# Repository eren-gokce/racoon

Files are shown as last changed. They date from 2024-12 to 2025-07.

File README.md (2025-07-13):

# Roket Aviyonik 🚀

### Güncel :

<details> <summary> Watchdog </summary>

Interrupt Watchdog (IWDT)
RTC Watchdog Timer (RTC_WDT)

ESP32 mimarisinde iki önemli sistem watchdog’u olan Interrupt Watchdog (IWDT) ve RTC Watchdog Timer (RTC_WDT), 
uygulama koduna herhangi bir müdahaleye gerek kalmadan sistem seviyesinde otomatik olarak çalışmaktadır.
IWDT, FreeRTOS işletim sistemi tarafından her tick’te beslenerek, ISR’ların veya kritik bölümlerin sistemin kilitlenmesine neden olup olmadığını denetler. 
RTC_WDT ise, sistem açıldığında (boot aşamasında) devreye girerek, main() fonksiyonuna zamanında ulaşılamazsa otomatik reset işlemi gerçekleştirir. 
Bu iki watchdog, ESP32 sisteminin kararlı çalışmasını sağlamakta, olası kilitlenmelerde sistemin kendi kendine toparlanmasına imkân tanımaktadır.

Task Watchdog Timer (TWDT)

ESP32 platformunda kullanılan Task Watchdog Timer (TWDT), belirli görevlerin (task'ların) belirli bir süre içerisinde düzgün şekilde 
çalışıp çalışmadığını denetlemek amacıyla kullanılan bir yazılımsal koruma mekanizmasıdır. 
Kullanıcı tarafından başlatılarak aktif hâle getirilen TWDT’ye, izlenmesi istenen görevler abone edilir. 
Bu görevler, belirlenen zaman aralığında esp_task_wdt_reset() fonksiyonu ile watchdog'u “beslemeli”; aksi takdirde 
TWDT bu görevin kilitlendiğini varsayarak sistemin hata mesajı üretmesini (panic) ya da resetlenmesini sağlar.
Güvenlik-kritik uygulamalarda TWDT, sistemin ana görevlerinin donması, veri akışının kesilmesi veya 
infinite loop gibi yazılım hatalarının oluşması durumunda müdahale ederek sistemin kendi kendini kurtarabilmesini sağlar.

```cpp
#include "esp_task_wdt.h"

void setup() {
  // ... mevcut kurulumlar ...

  esp_task_wdt_config_t twdt_config = {
    .timeout_ms = 3000, // 3 saniye içinde resetlenmeli
    .idle_core_mask = 0, // idle task izlenmiyor
    .trigger_panic = true
  };

  esp_task_wdt_init(&twdt_config); // Watchdog’u başlat
  esp_task_wdt_add(NULL);          // Mevcut görev (loop task) TWDT’ye abone edildi
}

void loop() {
  // Uçuş kontrol fonksiyonlarını çağır
  kalkis();
  burnout();
  apogee();
  parasut();
  alcalma();
  call_lora();

  esp_task_wdt_reset(); // 🔁 watchdog'u besle

  delay(200);
}
```
</details>

## [Yapılcaklar notu](https://ostimteknikuniversitesi-my.sharepoint.com/:w:/g/personal/230201060_ostimteknik_edu_tr/EbsuAKLU0ShNoTfdPXoBlwgBV6bBdwqXOMXw21tmuLnfXQ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)

<details> <summary> old  </summary>

güncel Algo flowchart
güncel Algo flowchart
	
- [Eski Arayüz Reposu](https://github.com/CerenSultanCETIN/RocketInterface13.git)

<div style="display: flex; justify-content: center; gap: 20px;">
  <a href="https://github.com/user-attachments/assets/b3c92df3-6dc9-4abe-9a28-f702d46e05a6">
    resim1
  </a>
<div style="display: flex; justify-content: center; gap: 20px;">
  <a href="https://github.com/user-attachments/assets/648fd35b-3c85-447b-8fb1-8ce616d4887b">
    resim1
  </a>

### 2025.04.27 KTR şablonundan olan görevlerim : 

- Özgün UKB’lerin algoritmaları açık ve net bir şekilde açıklanmalıdır.
 Algoritma açıklanırken karmaşık ve uzun cümleler kullanılmamalı,
 akış şemaları kullanılmalıdır. 
Kullanılan algoritmaya ilişkin akış şemasında; 
algoritmada kullanılan parametrelerin hangi sensörden geldiği açık ve net bir şekilde anlatılmalıdır.
 Kurtarma sistemini tetikleyecek parametreler listelenmeli ve neden seçildiği belirtilmelidir (kullandığı parametreleri doğru sensörlerden almayan veya eksik olarak açıklayan takımlar diskalifiye edilecektir). 
Algoritma içerisinde haberleşme ve yer istasyonu ile ilgili adımlar var ise bunlar paylaşılmamalıdır.
 (besma // görselleştirerek yap)

- Özgün UKB’lerin test edilmesi kapsamında test cihazı ile Ö-UKB arasında çalışacak olan yazılımın UKB ana algoritması ile nasıl entegre edildiği ve çalışma yapısı açık şekilde algoritma şeması olarak paylaşılmalıdır. (semih/enes/besma)

### 2025.04.26
Deney videosu (Semih) 
https://drive.google.com/drive/folders/1odC9xmdg6W0WZIL8I4gqv5UqY6kFndTy?usp=sharing

### 2025.04.24 Mete başkana algoritma hakkında soru soruldu ve bunun çıktısı şöyle oldu : 

🌟 Özet Strateji:

🧠 Sensör Füzyonlama (Sensor Fusion) + 📉 Kalman Filtresi

Bu iki yöntem, farklı sensörlerden gelen verileri birleştirerek daha doğru ve güvenilir ölçümler sağlar.

⸻

💡 Elimizdeki Üç Faktör:
	1.	İvme (Accelerometer)
	•	Başlangıç ve motor bitimi (burn-out) sırasında yüksek titreşim nedeniyle barometre bozulabilir.
	•	Bunu kontrol etmek için ivmeölçer (accelerometer) kullanılır.
	•	Kalman filtresi ile filtrelenerek anlık ivme patlamalarına karşı önlem alınır.
	2.	Dikey Hız (Vertical Speed)
	•	Barometre verisinden veya ivme verisinin integralinden hesaplanabilir.
	•	Özellikle motor kapanışından sonra roketin apogee noktasına ulaşıp ulaşmadığı burada anlaşılır.
	3.	Yükseklik (Altitude)
	•	Barometrik sensör (BMP280 gibi) ile ölçülür ama burn-out ve ani basınç değişimlerinde güvenilirliği düşer.
	•	Bu nedenle ivme ve dikey hız verisiyle çapraz kontrol yapılır.

⸻

🔍 Neden Kalman Filtresi?

Kalman filtresi, sistemdeki gürültülü sensör verilerini birleştirerek en iyi tahmini yapar. Yani:
	•	Barometre + ivmeölçer verisi → Yükseklik ve dikey hızın en güvenilir hali elde edilir.
	•	Başlangıçta barometredeki hataları ivme ile check edersiniz.
	•	Hata varsa Kalman filtresi bunu “güvenilir olmayan veri” olarak değerlendirip tahminini düzeltir.

⸻

🔄 Sensör Füzyonlama
	•	Sensör füzyonlama, farklı kaynaklardan gelen verileri birleştirerek tek bir anlamlı veri seti üretir.
	•	Örneğin:
	•	BMP280 (yükseklik)
	•	MPU6050 (ivme ve gyro)
	•	Kalman filtresi ile bu sensörlerin birleşimi yapılır.

⸻

📌 Uygulamada Ne Yapılmalı?
	1.	MPU6050 → ivme ve gyro verisini oku.
	2.	BMP280 → basınca dayalı yükseklik verisini al.
	3.	Tüm bu verileri Kalman filtresi ile işleyerek:
	•	Gerçek yükseklik
	•	Dikey hız
	•	Apogee tespiti
gibi önemli bilgileri güvenilir şekilde elde et.

---

📌 KTR Raporunda Algoritma’dan Ne Bekleniyor?

- 📄 “Özgün UKB’lerin algoritmaları açık ve net bir şekilde açıklanmalıdır.”
- 📄 “Algoritma açıklanırken karmaşık ve uzun cümleler kullanılmamalı, akış şemaları kullanılmalıdır.”
- 📄 “Algoritmada kullanılan parametrelerin hangi sensörden geldiği açık ve net bir şekilde anlatılmalıdır.”
- 📄 “Kurtarma sistemini tetikleyecek parametreler listelenmeli ve neden seçildiği belirtilmelidir.”
- 📄 “Algoritma içerisinde haberleşme ve yer istasyonu ile ilgili adımlar var ise bunlar paylaşılmamalıdır.”

### 2025.04.20 / Algoritma Deney Testi / Asansör Kullanıldı hızın değişimi gözlemlendi. ( Erenle birlikte yaptık )
##### KTR de bu kısımda bizden istenilen şu şekilde yazılmış: 

- Algoritma Testleri:
Bu test ile takimlar özgün UKB'leri ile aym sensör mimarisine sahip bir prototip olusturmalidir. Prototip için devre kartinin üretilmis olmasi gerekmemektedir. Sensörler modül olarak breadboard üzerinde bir araya getirilebilir. Devre kartini üretmis olan takimlar nihai devre kartlari ile bu testi gerçeklestirebilirler.
Testin amaci ayrilma sistemini aktiflestirecek olan algoritmanin çalisma prensibinin kontrolüdür. Takimlar gerekirse algoritmalari için belirledikleri esik degerleri degistirerek ancak algoritma mantigini degistirmeden algoritmalarin1 test etmelidirler. Yapilan test sonucunda ayrilma sisteminin aktiflestirildigi görsel veya isitsel bir çikti ile gösterilmelidir.
Ornek bir test senaryosu olarak, ayrilma algoritmasinda roketin yer normali ile yaptigi açi ve irtifa degerini kullanan bir sistem için breadboard üzerine yerlestirilen bir prototip aviyonik sistemin yer ile yaptigi açi el ile degistirilebilir.
Sonrasinda ise sistem bir emis sistemi (örnegin elektrik süpürgesi) yardimiyla vakumlama yapip irtifa degisimi saglanabilir. Yapilan degisiklikler sonucun kurtarma sisteminin aktivasyonunu modellemek için bir LED lambas1 yakilabilir ya da bir ses sistemi (örnegin buzzer) aktive edilebilir. Yapilan bu adimlar en fazla 30 saniyelik bir video ile gösterilmelidir.

  https://github.com/user-attachments/assets/4e7f96be-68da-4bf2-be7a-c1ad1da02b06

  - BUNUN SESLENDİRİLMESİ YAPILMASI GEREKİYOR ASANSÖRDE ÇIKILDIĞINI VE ŞU AMAÇLA YAPILMASI GEREKTİĞİNİ SÖYLEYEN BİR MONTAJ 

<a href="https://github.com/user-attachments/assets/b571d8d4-8fc2-40d7-b4c7-0fd44b211a0b">
  
</a>
<a href="https://github.com/user-attachments/assets/4e7f96be-68da-4bf2-be7a-c1ad1da02b06">
  
</a>

### 💥 2025.03.15 / KTR Raporlarının hazırlanması 

#### Questions:

1. Kodlanış şekilleri, i2c mi SPI mı UART mı ?
2. Hazır kütüphane var mı yoksa driver mı yazılacak ?

<details> <summary> Alternatif Modül</summary> 
2025_01_25/27

GPS için araştırma sürecine girdim ancak araştırırken birkez daha aldığım GPS modülunu denemeye karar verdim, başka bir kodla EKTEDİR, Cerendeydi GPS getirdi bende test için eve getirdim. Pazartesi günü Yusuf ve Şenol hocalarla konuşmak için gideceğim Ömer de eşlik edecek inşallah o güne kadar detaylı bir GPS modül araştırma raporlamasını yapmış olur test etmiş olurum yeni kodu umarım lock olur. 

- [NEO-6M GPS MODÜL ile konum, hız, irtifa, tarih bilgisi alma | ESP VE ARDUİNO | TİNYGPS++ LİBRARY](https://www.youtube.com/watch?v=yDfn9ZEc5MA)
- [Videodaki verilen kod](https://drive.google.com/drive/folders/1Ig9ccjL5o0V9VCOxEw0sJ4Tpg6B3VTsB)
- [TinyGPS++ Library](https://github.com/mikalhart/TinyGPSPlus?tab=readme-ov-file)

--
{Elimizdeki GY-NEO6MV2 GPS Modülü}
Roket takımları genelde Adafruit Ultimate GPS Modülü veya elimizdeki GY-NEO6MV2 GPS Modülünü kullanmış 
benim beğendiğim  u-blox NEO-M8N-0 
---
Alternatif Modüller :
-----------------------------

Adafruit Ultimate GPS 

[ Adafruit Ultimate GPS Breakout - 66 channel w/10 Hz updates: Bu modül, yüksek hassasiyetli GPS verileri sağlar ve 10 Hz'e kadar güncelleme hızı sunar. Ayrıca, dahili veri kaydedici ve antene sahiptir.
](https://www.adafruit.com/product/5440)
----------------------------------------------------- --------
[ Adafruit Ultimate GPS Breakout with GLONASS + GPS - PA1616D: Bu model, hem GPS hem de GLONASS uydu sistemlerini destekler, bu sayede daha hızlı ve hassas konum belirleme imkanı sunar.](https://www.adafruit.com/product/746?utm_source=chatgpt.com)

Ublox GYGPSV1 NEO-8M GPS Modülü:
1. [Ublox GY-GPSV3 NEO-8M M8N GPS Modülü](https://www.robocombo.com/ublox-gy-gpsv3-neo-8m-m8n-gps-modulu--3196) 472,56 ₺

2. [u-blox NEO-M8N-0](https://www.mouser.com.tr/ProductDetail/u-blox/NEO-M8N-0?qs=zW32dvEIR3unZhZI0KRbew%3D%3D
)[DataSheet](https://www.mouser.com.tr/datasheet/2/1025/NEO_M8_FW3_DataSheet_UBX_15031086-3180589.pdf)

Beitian BN-220 GPS Modülü
1. [AddictiveRC](https://shop.addictiverc.com/products/beitian-bn-220-gps-module-3-6v-5-5v-ttl-level-dual-gnss-module-built-in-led-flash-for-rc-fpv-drone) $20

2. [AMAZON](https://www.amazon.com.tr/Rordigo-HMC5883-Glonass-Kurulum-Kullan%C4%B1m/dp/B0D37YDZNM) 845 ₺
   
3. [Beitian Dual BN-220 GPS GLONASS Anten Modülü TTL Seviye RC Drone Uçak](https://www.elecbee.com/tr-592-GPS-Module/tr-17610-Beitian-Dual-BN-220-GPS-GLONASS-Antenna-Module-TTL-Level-RC-Drone-Airplane 
)$17,59

4. [Tyro119 RC Drone FPV Yarışı için Beitian BN-220T GPS Modülü Çift Modülü](https://www.elecbee.com/tr-617-module-board/tr-17651-Beitian-BN-220T-GPS-Module-Dual-Module-for-Tyro119-RC-Drone-FPV-Racing) $14,32

Ublox ZED-F9P RTK GPS Modülü

-------------------------------------
başka gps modüllerine burdan bakabiliriz : 
https://www.mouser.com.tr/c/embedded-solutions/wireless-rf-modules/gnss-gps-modules/

---
</details>

-----

| **GPS Modülü** | **Kullanılan Protokoller** | **Hazır Kütüphane** | **Yazılım Platformu** | **Driver Gereksinimi** |
| --- | --- | --- | --- | --- |
| **Adafruit Ultimate GPS Breakout** | UART | **Adafruit GPS Kütüphanesi** ([GitHub](https://github.com/adafruit/Adafruit_GPS)) | Arduino, Python | Hayır, kütüphane mevcut. |
|  |  | **TinyGPS++ Kütüphanesi** ([GitHub](https://github.com/mikalhart/TinyGPSPlus)) | Arduino, ESP32, ESP8266 | Hayır, kütüphane mevcut. |
| **Adafruit Ultimate GPS + GLONASS (PA1616D)** | UART | **Adafruit GPS Kütüphanesi** ([GitHub](https://github.com/adafruit/Adafruit_GPS)) | Arduino, Python | Hayır, kütüphane mevcut. |
|  |  | **TinyGPS++ Kütüphanesi** ([GitHub](https://github.com/mikalhart/TinyGPSPlus)) | Arduino, ESP32, ESP8266 | Hayır, kütüphane mevcut. |
| **Ublox GY-GPSV3 NEO-8M** | UART | **u-blox C++/Python API** ([u-blox Docs](https://www.u-blox.com/en/docs/UBX-13003221)) | Arduino, STM32, Raspberry Pi, Python | Hayır, kütüphane mevcut. |
|  |  | **TinyGPS++ Kütüphanesi** ([GitHub](https://github.com/mikalhart/TinyGPSPlus)) | Arduino, ESP32, ESP8266 | Hayır, kütüphane mevcut. |
|  |  | **NeoGPS Kütüphanesi** ([GitHub](https://github.com/SlashDevin/NeoGPS)) | Arduino, AVR, ESP8266 | Hayır, kütüphane mevcut. |
| **Ublox NEO-6M GPS Modülü** | UART | **TinyGPS++ Kütüphanesi** ([GitHub](https://github.com/mikalhart/TinyGPSPlus)) | Arduino, ESP32, ESP8266, STM32 | Hayır, kütüphane mevcut. |
|  |  | **NeoGPS Kütüphanesi** ([GitHub](https://github.com/SlashDevin/NeoGPS)) | Arduino, AVR, ESP8266 | Hayır, kütüphane mevcut. |
|  |  | **u-blox C++/Python API** ([u-blox Docs](https://www.u-blox.com/en/docs/UBX-13003221)) | Arduino, Raspberry Pi, STM32, Python | Hayır, kütüphane mevcut. |
| **Beitian BN-220 GPS Modülü** | UART | **TinyGPS++ Kütüphanesi** ([GitHub](https://github.com/mikalhart/TinyGPSPlus)) | Arduino, ESP32, ESP8266 | Hayır, kütüphane mevcut. |
|  |  | **NeoGPS Kütüphanesi** ([GitHub](https://github.com/SlashDevin/NeoGPS)) | Arduino, AVR, ESP8266 | Hayır, kütüphane mevcut. |
| **Ublox ZED-F9P RTK GPS Modülü** | UART, I2C, SPI | **u-blox F9P RTK Kütüphanesi** ([u-blox Docs](https://www.u-blox.com/en/docs/UBX-21022705)) | Arduino, Raspberry Pi, STM32, Python | Hayır, kütüphane mevcut. |
|  |  | **TinyGPS++ Kütüphanesi** ([GitHub](https://github.com/mikalhart/TinyGPSPlus)) | Arduino, ESP32, ESP8266 | Hayır, kütüphane mevcut. |

### **Kütüphaneler ve Kullanım Alanları:**
| **Kütüphane** | **Platformlar** | **Avantajlar** | **Olası Sorunlar** |
| --- | --- | --- | --- |
| **TinyGPS++** | Arduino, ESP32, ESP8266 | Basit ve hızlı kullanım. Hızlı entegrasyon sağlar. | Bellek kısıtlaması olan projelerde yetersiz olabilir, örneğin düşük bellekli cihazlarda. |
| **NeoGPS** | Arduino, AVR, ESP8266 | Düşük bellek kullanımı, hızlı veri işleme. Gerçek zamanlı verileri işlemek için optimize edilmiştir. | Yapılandırması daha karmaşık olabilir, başlangıç seviyesindeki kullanıcılar için zorlayıcı olabilir. |
| **u-blox API** | Arduino, STM32, Raspberry Pi | Gelişmiş veri işleme, GNSS desteği, yüksek doğruluklu veriler sağlar. | Basit projelerde fazla karmaşık ve donanım gereksinimleri yüksek olabilir. Ayrıca, API'yi kullanmak için biraz daha fazla öğrenme süresi gerekebilir. |
| **u-blox F9P RTK** | Arduino, STM32, Raspberry Pi | RTK (Real-Time Kinematic) desteği, çoklu GNSS Global Navigation Satellite System) sistemlerini destekler, yüksek doğruluk sağlar (santimetre seviyesinde). | Yüksek maliyet, karmaşık yapılandırma, yüksek donanım gereksinimi. |

### 🤔🧐 2025_01_31 / ÖTR Rapor incelemesi ve geçmiş raporları inceleme notlarım: 

- Geçen sene finalist olan takım gps için [bunu](https://www.mouser.com.tr/ProductDetail/u-blox/MAX-8Q-0?qs=DPoM0jnrROXs29tEjk5Xmw%3D%3D) kullanmışlar güç tüketimi bakımından daha az olduğu ve daha hızlı güncelleme hızı için bunu kullandıklarını düşünüyordum Mete başkan " Fazla profesyonel bir ürün , Bunu kullanmamız zor olur. Önce elimizdekiyle işi bitirelim sonra geçmeyi deneriz" dedi.
- 

### 🌚🤝 2025_01_29 / Şartname toplantısı sonrası bazı notlar ve sorular:

- İrtifa 
- Enlem
- Boylam

bilgisi olmak zorunda.

- Jireskoptan gelen verinin birinimi dps mi ?
- Ivmenin birimi g-force mudur ?

yoksa başka bir şey olup onu dönüştürmemiz mi gerekir ?

<a href="(https://github.com/user-attachments/assets/f52d8408-84fa-4977-bce8-330be7c3f8ec)">
    resim7
  </a>

- USB -TTL olan bağlantı nasıl yapacağız onunla ilgili bir araştırma yapılmalı ? 
- yaptığımız form uygulamasını nasıl export edip onu desktop app yapmamız gerekiyor? 

- HYI denilen sistemin com bağlantı ayarları ile ilgili birkaç madde var onu anlamadık.

### 💥🤙 2025.01.27 / GPS ilk kez çalıştı !.. 

bu [kodu](https://github.com/eren-gokce/racoon/blob/main/gpsTest/gpsModuleVakasi.ino) denedik ve çalıştı. Veri aldık ancak şöyle bir durum var , [NMEA DECODER](https://swairlearn.bluecover.pt/nmea_analyser) da çevirmemiz ve o şekilde Latitude, Longitude, Time çıktılarını anlamamız gerekti.

<a href="https://github.com/user-attachments/assets/7f5c361f-0555-460b-aa46-07284a1dbdd8">
  resim1
</a>
<a href="https://github.com/user-attachments/assets/16cb8f80-afea-4d90-a05c-b67961d86f9f">
  resim2
</a>
<a href="https://github.com/user-attachments/assets/33fd836e-89a2-4c3f-a062-ecb3575717f9">
  resim3
</a>
<a href="https://github.com/user-attachments/assets/0d57ecf8-1266-4181-a1d9-74a077fec470">
  resim4
</a>
<details>
   
<summary> Plan Algoritması: GPS Verisinin Alınması, Decode Edilmesi ve Gösterimi </summary>

#### **1. Başlangıç**
- **Arduino'dan NMEA verisi alınması için gerekli seri port ayarlarını yap.**
  - COM port ve baud rate değerlerini belirle.
  - Seri portu açarak Arduino'dan veri okumayı başlat.

---

#### **2. Veri Alımı**
1. **Arduino'dan gelen veriyi seri port üzerinden oku.**
   - Her satırın bir NMEA cümlesi olduğunu varsay.
   - NMEA cümlelerini satır bazında al (ör. `$GPGLL`, `$GPRMC`).

2. **NMEA cümlelerini bir buffer içine kaydet.**
   - Cümle tamamlandığında (satır sonu `\n` görüldüğünde), decode işlemine geç.

---

#### **3. Decode İşlemi**
1. **Filtreleme:**
   - Gelen veriyi kontrol et.
   - Yalnızca `$GPGLL` veya `$GPRMC` cümlelerini işle.

2. **Veri Ayrıştırma:**
   - `NmeaParser` kullanarak cümleleri otomatik decode et.
     - `$GPGLL`: Latitude, Longitude, UTC Time.
     - `$GPRMC`: Latitude, Longitude, UTC Time ve ek olarak hız/yön bilgisi.
   - Ayrıştırılan değerleri geçerli formatta (ondalık derece) hesapla.

3. **Koordinatları Ondalık Dereceye Dönüştür:**
   - Latitude ve Longitude değerlerini derece/dakika formatından ondalık dereceye çevir.

---

#### **4. Arayüz Güncellemesi**
1. **Enlem, boylam ve zamanı arayüzde göster:**
   - Latitude, Longitude ve Time bilgilerini bir `TextBox` veya `Label` içinde güncelle.

2. **Harita Güncellemesi:**
   - Harita üzerindeki mevcut marker'ı temizle.
   - Yeni Latitude ve Longitude değerleriyle bir marker ekle.
   - Haritayı marker’ın bulunduğu konuma merkezle.

---

#### **5. Verilerin Yedeklenmesi**
1. **Ayrıştırılan tüm verileri bir CSV dosyasına yaz.**
   - Dosya mevcut değilse, başlık satırı ekle: `Latitude,Longitude,Time`.
   - Yeni bir veri alındığında, bu veriyi dosyaya ekle:
     ```
     Latitude, Longitude, Time
     39.968672, 32.743390, 13:45:16
     ```

2. **Veri güvenliği için dosya işlemlerini doğru yönet:**
   - Dosya açıkken hatalardan korunmak için try-catch bloğu kullan.

---

#### **6. Anlık Konum Takibi**
1. **Yeni veri geldiğinde mevcut veriyi geçersiz kıl:**
   - Haritada yalnızca en güncel veriyi göster.
   - Haritayı sürekli yeni gelen veriyle güncelle.

2. **Daha önce gelen tüm verileri CSV dosyasına sakla:**
   - Harita güncellenirken eski veriler kaybolmaz, yalnızca yedeklenir.

---

#### **7. Hata Yönetimi**
1. **Seri Port:**
   - Port açık değilse kullanıcıyı uyar ve programı durdur.
   - Hatalı port seçimi yapılırsa, kullanıcıya uygun mesaj göster.

2. **Decode İşlemi:**
   - Geçersiz bir NMEA cümlesi gelirse, işlemi atla ve bir sonraki satıra geç.

3. **Dosya İşlemleri:**
   - CSV dosyasına yazarken oluşabilecek hataları yönet.

---

#### **8. Programın Sonlandırılması**
- Seri port bağlantısını kapat.
- Haritayı son gösterilen konumda bırak.
- Yedeklenen veriler CSV dosyasında eksiksiz bir şekilde bulunmalı.

---

### **Algoritma Akışı**

```plaintext
Başla
↓
Seri portu aç ve GPS modülünden veri al
↓
Her satırı oku:
    Eğer `$GPGLL` veya `$GPRMC` ile başlıyorsa:
        → NmeaParser kullanarak veriyi ayrıştır
        → Latitude, Longitude ve UTC Time bilgilerini çıkar
        → Koordinatları ondalık dereceye dönüştür
        → Arayüzü güncelle: Enlem, Boylam ve Zaman bilgilerini göster
        → Haritada konumu güncelle: Marker ekle ve haritayı merkeze al
        → Veriyi `gps_data.csv` dosyasına yedekle
    Değilse:
        → Bir sonraki satıra geç
↓
Yeni veri geldikçe işlemi tekrarla
↓
Hata varsa kullanıcıyı bilgilendir
↓
Program sonlandırıldığında:
    → Seri portu kapat
    → Haritayı ve CSV dosyasını kaydet
Bitti
```

---

</details>

<details><summary>Plan: Seri Porttan Gelen NMEA Verisini Otomatik Decode Etme ve İşleme </summary>
   
###### **1. Gerekenler**
- **Kütüphaneler:**
  1. **NmeaParser**:
     - NMEA verilerini otomatik olarak ayrıştırmak için kullanılır.
     - `$GPGLL`, `$GPRMC`, `$GPGGA` gibi standart NMEA cümlelerini destekler.
     - **Yükleme:** 
       ```bash
       Install-Package NmeaParser
       ```
  2. **GMap.NET**:
     - Harita üzerinde konum göstermek için kullanılır.
     - Google Maps, OpenStreetMap gibi sağlayıcılardan veri alır.

- **Donanım:**
  - Arduino + GPS modülü
  - Bilgisayara USB ile bağlı Arduino cihazı

---

###### **2. Uygulama Akışı**

1. **Seri Porttan Veri Alımı:**
   - Arduino, GPS modülünden aldığı NMEA cümlelerini seri port üzerinden bilgisayara gönderir.
   - C# uygulaması, bu verileri seri port dinleyicisiyle alır.

2. **NMEA Verisinin Decode Edilmesi:**
   - Tüm NMEA cümleleri `NmeaParser` ile işlenir.
   - `$GPGLL` veya `$GPRMC` cümlelerinden:
     - **Latitude** (Enlem),
     - **Longitude** (Boylam),
     - **UTC Time** bilgileri ayrıştırılır.

3. **Harita Üzerinde Gösterim:**
   - Ayrıştırılan Latitude ve Longitude bilgileri, **GMap.NET** kullanılarak harita üzerinde marker (işaretleyici) olarak gösterilir.
   - Harita, yeni konuma göre merkezlenir.

4. **Verilerin Yedeklenmesi:**
   - Decode edilen tüm veriler, bir CSV dosyasına şu formatta kaydedilir:
     ```
     Latitude, Longitude, Time
     ```

---

###### **3. Teknik Detaylar**

##### **A. NMEA Verisini Decode Etme**
1. **$GPGLL Cümlesi:**
   - **Format:** `$GPGLL,<latitude>,<N/S>,<longitude>,<E/W>,<UTC time>,<status>,<checksum>`
   - Örnek:
     ```
     $GPGLL,3958.12035,N,03244.60339,E,134516.00,A*61
     ```
   - Ayrıştırılacak Değerler:
     - `Latitude`: 39°58.12035' N → 39.96867267
     - `Longitude`: 32°44.60339' E → 32.74339065
     - `UTC Time`: 13:45:16

2. **$GPRMC Cümlesi:**
   - **Format:** `$GPRMC,<UTC time>,<status>,<latitude>,<N/S>,<longitude>,<E/W>,<speed>,<course>,<date>,...`
   - Örnek:
     ```
     $GPRMC,134517.00,A,3958.12036,N,03244.60344,E,0.601,,270125,,,A*74
     ```
   - Ek olarak:
     - Hız bilgisi `speed` ve yön bilgisi `course` ayrıştırılabilir.

3. **Ondalık Dereceye Dönüştürme:**
   - Derece/Dakika formatını ondalık dereceye dönüştürmek için:
     ```csharp
     private double ConvertToDecimal(string degreeString, string direction)
     {
         double degrees = double.Parse(degreeString.Substring(0, 2));
         double minutes = double.Parse(degreeString.Substring(2));
         double decimalDegrees = degrees + (minutes / 60);

         if (direction == "S" || direction == "W")
             decimalDegrees *= -1;

         return decimalDegrees;
     }
     ```

---

###### **B. Haritada Gösterim**
1. **GMap.NET Harita Ayarları:**
   ```csharp
   private void InitializeMap()
   {
       gMapControl1.MapProvider = GMapProviders.GoogleMap; // Harita sağlayıcı
       GMaps.Instance.Mode = AccessMode.ServerOnly;
       gMapControl1.Position = new PointLatLng(39.92077, 32.85411); // Başlangıç pozisyonu
       gMapControl1.MinZoom = 1;
       gMapControl1.MaxZoom = 20;
       gMapControl1.Zoom = 15;

       markersOverlay = new GMapOverlay("markers");
       gMapControl1.Overlays.Add(markersOverlay);
   }

   private void UpdateMap(double latitude, double longitude)
   {
       markersOverlay.Markers.Clear(); // Eski markerları temizle
       PointLatLng point = new PointLatLng(latitude, longitude);
       GMarkerGoogle marker = new GMarkerGoogle(point, GMarkerGoogleType.red_dot);
       markersOverlay.Markers.Add(marker);
       gMapControl1.Position = point;
   }
   ```

2. **Marker Güncelleme:**
   - Yeni konum geldiğinde marker haritada güncellenir ve harita otomatik olarak merkezlenir.

---

##### **C. Verilerin Yedeklenmesi**
1. **CSV Formatında Kaydetme:**
   ```csharp
   private void SaveToCsv(double latitude, double longitude, string utcTime)
   {
       string filePath = "gps_data.csv";

       if (!File.Exists(filePath))
       {
           File.WriteAllText(filePath, "Latitude,Longitude,Time\n"); // Başlık satırı
       }

       File.AppendAllText(filePath, $"{latitude},{longitude},{utcTime}\n");
   }
   ```

2. **Her Yeni Veri Geldiğinde Kaydetme:**
   - `$GPGLL` veya `$GPRMC` cümlesi decode edildikten sonra, bu fonksiyon çağrılır.

---

##### **4. Özet**
- **Kütüphaneler:**
  1. `NmeaParser`: NMEA cümlelerini decode etmek için.
  2. `GMap.NET`: Harita üzerinde konum göstermek için.

- **Uygulama Akışı:**
  1. Arduino’dan seri port üzerinden NMEA verileri alınır.
  2. `$GPGLL` veya `$GPRMC` cümleleri filtrelenir.
  3. Latitude, Longitude ve Time bilgileri ayrıştırılır.
  4. Decode edilen veriler:
     - Harita üzerinde marker olarak gösterilir.
     - `gps_data.csv` dosyasına kaydedilir.
</details>
<details>

<summary> Örnek kod GPT: </summary>

using System;
using System.IO.Ports;
using System.Windows.Forms;
using GMap.NET;
using GMap.NET.MapProviders;
using GMap.NET.WindowsForms;
using GMap.NET.WindowsForms.Markers;
using System.IO;
using NmeaParser;
using NmeaParser.Messages;
public partial class MainForm : Form
{
    private SerialPort serialPort;
    private GMapOverlay markersOverlay;

    public MainForm()
    {
        InitializeComponent();
        InitializeMap();
    }

    // 1. Harita Başlangıç Ayarları
    private void InitializeMap()
    {
        gMapControl1.MapProvider = GMapProviders.GoogleMap; // Google Maps sağlayıcı
        GMaps.Instance.Mode = AccessMode.ServerOnly;
        gMapControl1.Position = new PointLatLng(39.92077, 32.85411); // Ankara başlangıç pozisyonu
        gMapControl1.MinZoom = 1;
        gMapControl1.MaxZoom = 20;
        gMapControl1.Zoom = 15;

        markersOverlay = new GMapOverlay("markers");
        gMapControl1.Overlays.Add(markersOverlay);
    }

    // 2. Seri Port Bağlantısını Aç
    private void btnConnect_Click(object sender, EventArgs e)
    {
        serialPort = new SerialPort
        {
            PortName = cmbPorts.Text, // Kullanıcıdan seçilen COM port
            BaudRate = 9600,
            DataBits = 8,
            Parity = Parity.None,
            StopBits = StopBits.One
        };

        serialPort.DataReceived += SerialPort_DataReceived; // Veri geldiğinde tetiklenecek
        serialPort.Open();
        MessageBox.Show("Bağlantı Başarılı!");
    }

    // 3. Seri Port Bağlantısını Kapat
    private void btnDisconnect_Click(object sender, EventArgs e)
    {
        if (serialPort != null && serialPort.IsOpen)
        {
            serialPort.Close();
            MessageBox.Show("Bağlantı Kapatıldı!");
        }
    }

    // 4. Seri Port Üzerinden Veri Al
    private void SerialPort_DataReceived(object sender, SerialDataReceivedEventArgs e)
    {
        string nmeaData = serialPort.ReadLine();
        try
        {
            var message = NmeaMessage.Parse(nmeaData); // NmeaParser ile ayrıştırma

            if (message is Gll gll) // Eğer $GPGLL mesajı geldiyse
            {
                ProcessGllMessage(gll);
            }
            else if (message is Rmc rmc) // Eğer $GPRMC mesajı geldiyse
            {
                ProcessRmcMessage(rmc);
            }
        }
        catch (Exception ex)
        {
            Console.WriteLine($"Decode hatası: {ex.Message}");
        }
    }

    // 5. GPGLL Mesajını İşle
    private void ProcessGllMessage(Gll gll)
    {
        double latitude = gll.Latitude;
        double longitude = gll.Longitude;
        string time = gll.Time.ToString();

        // Arayüz Güncelle
        UpdateUI(latitude, longitude, time);

        // Haritada Göster
        UpdateMap(latitude, longitude);

        // CSV'ye Kaydet
        SaveToCsv(latitude, longitude, time);
    }

    // 6. GPRMC Mesajını İşle
    private void ProcessRmcMessage(Rmc rmc)
    {
        double latitude = rmc.Latitude;
        double longitude = rmc.Longitude;
        string time = rmc.FixTime.ToString();

        // Arayüz Güncelle
        UpdateUI(latitude, longitude, time);

        // Haritada Göster
        UpdateMap(latitude, longitude);

        // CSV'ye Kaydet
        SaveToCsv(latitude, longitude, time);
    }

    // 7. Arayüzü Güncelle
    private void UpdateUI(double latitude, double longitude, string time)
    {
        this.Invoke((MethodInvoker)delegate
        {
            txtLatitude.Text = latitude.ToString("F6");
            txtLongitude.Text = longitude.ToString("F6");
            txtTime.Text = time;
        });
    }

    // 8. Haritayı Güncelle
    private void UpdateMap(double latitude, double longitude)
    {
        markersOverlay.Markers.Clear(); // Önceki markerları temizle
        PointLatLng point = new PointLatLng(latitude, longitude);
        GMarkerGoogle marker = new GMarkerGoogle(point, GMarkerGoogleType.red_dot);
        markersOverlay.Markers.Add(marker);
        gMapControl1.Position = point;
    }

    // 9. CSV Dosyasına Kaydet
    private void SaveToCsv(double latitude, double longitude, string utcTime)
    {
        string filePath = "gps_data.csv";

        if (!File.Exists(filePath))
        {
            File.WriteAllText(filePath, "Latitude,Longitude,Time\n"); // Başlık satırı
        }

        File.AppendAllText(filePath, $"{latitude},{longitude},{utcTime}\n");
    }
}

</summary>
</details>

----

<details>
   <summary>Yazılım ve Donanım Arasındaki Haberleşme Mantığını anlamak için yaptığım deneylerin döküman repoları :  </summary>
(about one month ago)

1. [LedBlinkingCsharpArduino](https://github.com/besmabakirci1/LedBlinkingCsharpArduino/tree/main)
2. [Real-Time-Data-Visualization-with-BMP280-and-cSharp](https://github.com/besmabakirci1/Real-Time-Data-Visualization-with-BMP280-and-cSharp/tree/master)
--
</details>
<details>
<summary> 2025_01_07 / versiyon hatası ve çalışmayan GPS </summary> 

🕙09:00-15:28

groundStation.cs 26th line there is "private GMapControl gmapcontrol = new ; " line getting unhendeled exception error aldığımız hatayı bir türlü çözemedik versiyon hatasından kaynaklı bir exception error alıyoruz gpt sorduk araştırdık diğer insanların yaptığı repoları inceledim lakin işe yarar bir çıktı alamadık.

Bulduğumuz işe yarayabilir repolar :
------------------------------------
- [1.REPO](https://github.dev/noant/Lazurite/blob/f8575b9de67a86cb28040c8db34052900a726641/Lazurite/LazuriteUI.Windows.Main/Statistics/Views/GeolocationViewImplementation/Locat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)
- [2.REPO](https://github.dev/AliFlux/VectorTileRenderer/blob/b76ccdd010bb1f6b6a8c749d8c0f261977013a20/Gmap.Demo.WinForms/Form1.cs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)
- [3.REPO](https://github.dev/disdain13/PokeRoadie/blob/d40914458baf29796c5d31ba5e2cfe703d536ca3/PokeRoadie/Forms/MainForm.cs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)

   Alınan Hata : Could not load type 'GMap.NET.Singleton`1' from assembly 'GMap.NET.Core, Version=2.1.6.0, Culture=neutral, PublicKeyToken=b85b9027b614afef'
      NOT : Hata .Net uzantılı bir proje oluşturduğumuzda giderildi. Ceren Hanıma sevgilerimizle :) 

Gps satın almıştım onu denemeye çalıştık ama açık havada olması gerektiğinden olumlu bir çıktı alamadık, çalışıp çalışmadığını bilmiyoruz.
   
🕞 15:30-18:28  

Yanıp sönmeye başladı ama hiç bir şey yazdırmıyo
Sinyal kontolü için bunu denedim Rx Tx değiştirip 10 11 yaptım.
Rx Tx 10 (eskiden 3 yaptim calismadi port okuyor ama yok ) 
Tx Rx 11 (eskiden 4 yaptim calismadi port okuyor ama yok)
Gnd Gnd
Vcc 5v 

dışarda çok beklememe rağmen çalışmadı, bir yerlerim dondu :/ sağlık olsun ne yapalım efenim.. yarın terasta deneyeceğiz cerenle :) umarım olur.

[Gps Module Vakası Repom](https://github.com/besmabakirci1/gpsModuleVakasi/tree/main)
</details>

# [ Ömer Faruk Çift & Berru Erkul, Once Said ] 

## ⚡️ Roket Uçuş Algoritması Açıklaması
### FLOWCHART ÖTR İÇİN 
ötr için drawio (1)

### FLOWCHART Bizim için
roketcimms drawio

### Kütüphaneler
Kodda kullanılan temel kütüphaneler şunlardır:

- `Adafruit_MPU6050.h`: **MPU6050** ivmeölçer ve jiroskop sensörü için Adafruit kütüphanesi.
- `Adafruit_BMP280.h`: **BMP280** barometrik basınç sensörü için Adafruit kütüphanesi.
- `Adafruit_Sensor.h`: Adafruit'in sensör arabirimi.
- `Wire.h`: **I2C** haberleşme için kullanılan kütüphane.
- `SPI.h`: **SPI** haberleşme kütüphanesi.

## Değişkenler ve Kalman Filtresi

<details> <summary> Değişkenler </summary>
  
```cpp
float Q = 0.001; // Süreç gürültü kovaryansı
float R = 0.03;  // Ölçüm gürültü kovaryansı
float P = 1;     // Hata kovaryansı
float K;         // Kalman kazancı
float filteredX = 0, filteredY = 0, filteredZ = 0;
float axOffset = 0, ayOffset = 0, azOffset = 0;
float gxOffset = 0, gyOffset = 0, gzOffset = 0;
float baseAltitude = 0;
float h = bmp.readAltitude(1030.9);
float a = sqrt(pow(axOffset, 2) + pow(ayOffset, 2) + pow(azOffset, 2));
```

- **Kalman Filtresi** kullanılarak sensör verileri gürültüden arındırılır.
- **Kovaryans**, iki değişkenin birbirleriyle nasıl değiştiğini ölçen bir istatistiksel değerdir; pozitifse aynı yönde, negatifse ters yönde değiştiklerini gösterir.
</details>

<details> <summary> Kalman Filtre Fonksiyonu </summary>

  ```cpp
float applyKalmanFilter(float measurement, float &estimate) {
    P += Q;
    K = P / (P + R);
    estimate = estimate + K * (measurement - estimate);
    P *= (1 - K);
    return estimate;
}
```

- `applyKalmanFilter` fonksiyonu, ölçülen veriyi süzerek daha doğru bir tahmin üretir.

</details>

## Sensör Kalibrasyonu
<details> <summary> Sensör Kalibrasyon Kodu </summary>

```cpp
void sensorKalibrasyonu() {
    Serial.println("Sensör kalibrasyonu başlatılıyor");
    sensors_event_t a, g, temp;
    int calibrationLoops = 1000;

    for (int i = 0; i < calibrationLoops; i++) {
        mpu.getEvent(&a, &g, &temp);
        axOffset += a.acceleration.x;
        ayOffset += a.acceleration.y;
        azOffset += a.acceleration.z;
        gxOffset += g.gyro.x;
        gyOffset += g.gyro.y;
        gzOffset += g.gyro.z;
        delay(5);
    }

    axOffset /= calibrationLoops;
    ayOffset /= calibrationLoops;
    azOffset /= calibrationLoops;
    gxOffset /= calibrationLoops;
    gyOffset /= calibrationLoops;
    gzOffset /= calibrationLoops;
    baseAltitude = bmp.readAltitude(1030.9);
    Serial.println("Kalibrasyon tamamlandı.");
}
```
- Sensör verilerinin **ortalaması** alınarak **gürültü azaltılır**.
- **MPU6050** ve **BMP280** için referans değerler belirlenir.
  
</details>

## MPU ve BMP Kontrol Fonksiyon

<details><summary> MPU ve BMP Kontrol Fonksiyon Kodu </summary>
  
Bu fonksiyonlar **MPU6050** ve **BMP280** sensörlerinin çalışıp çalışmadığını kontrol eder.

```cpp
void MPU() {
    for (int i=0; i<3; i++) {
        if (!mpu.begin()) {
            Serial.println("Failed to find MPU6050 chip");
            MPU(); // Çalışmazsa tekrar başlat
        }
    }
    Serial.println("MPU çalışmaya hazır");
}
```

```cpp
void BMP() {
    unsigned status = bmp.begin(0x76);
    for (int i=0; i<3; i++) {
        if (!status) {
            Serial.println(F("BMP280 sensörü bulunamadı!"));
            while (1) delay(10);
        }
    }
}
```
</details>

## Uçuş Algoritması Fonksiyonları

<details><summary> roketHareketEtmiyor, LiffOff , Apogee , Paraşüt Açılma Kontrolü , Roket Yere İndiğinde Kontrol </summary>

### Roket Hareket Etmezse
```cpp
void roketHareketEtmiyor() {
    if(h==){
    axOffset = sensor.acceleration.x;//offsetleri sabitliyoruz değer alınmıyo
    ayOffset = sensor.acceleration.y;
    azOffset = sensor.acceleration.z;
    gxOffset = sensor.gyro.x;
    gyOffset = sensor.gyro.y;
    gzOffset = sensor.gyro.z;
}
    else{ // uçmaya başlarsa kalibrasyondaki ofsetleri bir kere alıp devam ediyoruz sensor kalibrasyonundaki kod
        mpu.getEvent(&a, &g, &temp);
        axOffset += a.acceleration.x;
        ayOffset += a.acceleration.y;
        azOffset += a.acceleration.z;
        gxOffset += g.gyro.x;
        gyOffset += g.gyro.y;
        gzOffset += g.gyro.z;
        delay(500);

    axOffset /= calibrationLoops;
    ayOffset /= calibrationLoops;
    azOffset /= calibrationLoops;
    gxOffset /= calibrationLoops;
    gyOffset /= calibrationLoops;
    gzOffset /= calibrationLoops;

    referansYukseklik = bmp.readAltitude(1030.9); // Referans yükseklik alınması
    }
```
 Eğer roket kalibrasyonu tamamladıktan sonra uçuşa geçmezse uygulanacak tarife   
 
### Liff Off 

```cpp
void LiffOff(){// Başlangıç noktası

for (int i=0; i<3; i++){
  if (h>referansYukseklik && a> kalibrasyondan alınan ivme){// ivmeyi bilemedik 
    delay(100);
  }
  else {
    roketHareketEtmiyor();
    delay(10000);
    LiffOff();
  }
}
  Serial.println("ucus saglandi");
}
}
```
 Roketin belirli bir yükseklik ve ivme eşiğini geçtiğinde uçuş moduna geçtiğini belirler.

### Apogee (Tepe Noktası)
  
```cpp
void apogee() {
    for (int i=0; i<3; i++) {
        if (pitch < 0 && dikey hız <= 0 && h1 < h2) {
            delay(500);
        } else {
            delay(500);
            apogee();
        }
    }
    Serial.println("Apogee ulaşıldı");
}
```
 Roketin **apogee'ye ulaşıp ulaşmadığını** kontrol eder.
  
### Paraşüt Açılma Kontrolü

  ```cpp
void parasut2() {
    for (int i=0; i<3; i++) {
        if (400 < h && h < 600) {
            delay(500);
        } else {
            delay(500);
            parasut2();
        }
    }
    Serial.println("İkinci paraşüt açılabilir");
}
```

 **400m ile 600m** arasında ikinci paraşütün açılmasına izin verir.

### Roket Yere İndiğinde Kontrol  
  
```cpp
void alcalmaKontrol() {
    for (int i=0; i<3; i++) {
        if (h1 == h2 && dikey hız == 0 && a == 0) {
            delay(500);
        } else {
            delay(500);
            alcalmaKontrol();
        }
    }
    Serial.println("Roket yerde, GPS verisi alın");
}
```

</details>

## Ana `setup` ve `loop`
  
### `setup` Fonksiyonu
- Sensörleri başlatır.
- Kalibrasyon işlemlerini gerçekleştirir.
- `MPU`, `BMP`, `GPS` ve `lora` modüllerini kontrol eder.

### `loop` Fonksiyonu
- **MPU6050** ve **BMP280**'den verileri okur ve **Kalman filtresi** uygular.
- Uçuşun her aşamasını denetleyerek **uçuş kontrolü**, **apogee**, **paraşüt açılma** ve **iniş kontrolü** fonksiyonlarını çalıştırır.
- Roketin yere indiğinde GPS verisini kaydeder.

## 🪡 EEPROM, **GPS** ve **LoRa** modüllerinin entegrasyonu daha sonra eklenecek.
----

# [ Eren Gökçe, Once Said ] 

## [Yaptıklarımı not aldığım link](https://docs.google.com/document/d/1Ugchummm-yzFRAeQpJfb2bQv5UT_bcpwTwR8XtCUR0M/edit?usp=sharing)

</details>

- [Teknofest şartnamesi](https://cdn.teknofest.org/media/upload/userFormUpload/TEKNOFEST-2025_Roket_Yar%C4%B1%C5%9Fmas%C4%B1_%C5%9Eartnamesi_PfkB5.pdf)

- [Hakem yer istasyonu şartnamesi](https://github.com/user-attachments/files/18579452/EK-7_Hakem_Yer_Istasyonu_y52A5.1.docx)

- [Yeni Arayüz](https://github.com/besmabakirci1/RocketUI2025)

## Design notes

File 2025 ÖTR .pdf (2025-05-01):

Herkese Açık | Public

# TEKNOFEST-2025 ROKET YARIŞMASI Orta İrtifa Kategorisi Ön Tasarım Raporu (ÖTR) Sunuşu

# Takım Adı

5 Şubat 2025 Çarşamba | 1

### 2025 TEKNOFEST ROKET YARIŞMASI ÖN TASARIM RAPORU (ÖTR)

1 | 1

# Takım Yapısı

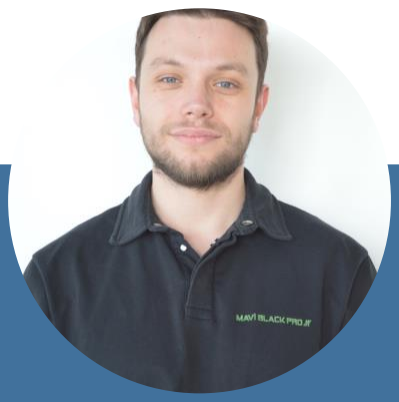
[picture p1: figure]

5 Şubat 2025 Çarşamba | 2

### 2025 TEKNOFEST ROKET YARIŞMASI ÖN TASARIM RAPORU

Öğr. Gör. Fatih BAYKAL
Takım danışmanı
İHA ve Operatörlüğü
Ostim Teknik
Üniversitesi

Turgut ŞAHİN
Takım Kaptanı
Metalurji ve Malzeme
Mühendisliği
Gazi Üniversitesi

Mustafa Enes ÖZTÜRK
Aviyonik Üyesi
Elektrik Elektronik
Mühendisliği
Ostim Teknik Üniversitesi

Besma BAKIRCI
Sponsorluk-Dokümantasyon
Bilgisayar Mühendisliği
Ostim Teknik Üniversitesi

Yahya Furkan USLU
Aerodinamik-Analiz Sorumlusu
Havacılık ve Uzay Mühendisliği Ostim Teknik Üniversitesi

Muhammed Batuhan ÜNAL
Mekanik Kaptanı
İmalat Mühendisliği
Gazi Üniversitesi

Mete Kağan IŞIKLI
Aviyonik Kaptanı
Elektrik Elektronik
Mühendisliği
Gazi Üniversitesi
1 | 2

# Yarışma Roketi Genel Bilgiler

5 Şubat 2025 Çarşamba | 3

# Tahmin Edilen Uçuş Verileri ve Analizleri

## Ölçü

Boy (mm): | 2550 mm
Çap (mm): | 130 mm
Roketin Kuru Ağırlığı (g): | 17842 g
Yakıt Kütlesi (g): | 3951 g
Motorun Kuru Ağırlığı (g): | 2742 g
Faydalı Yük Ağırlığı (g): | 4100 g
Toplam Kalkış Ağırlığı (g): | 21793 g

## Ölçü

Kalkış İtki/Ağırlık Oranı: | 5.3
Rampa Çıkış Hızı (m/s): | 32.8 m/s
Stabilite (0.3 Mach için): | 1.89 cal
En büyük ivme (g): | 10.3 G
En Yüksek Hız (m/s): | 279 m/s

## En Yüksek Mach Sayısı:

0,836
Tepe Noktası İrtifası (m): | 3457 m

# Yarışma Roketi Hakkında Genel Bilgiler

## Aerotech M1850

# Motor

### 2025 TEKNOFEST ROKET YARIŞMASI ÖN TASARIM RAPORU

# Genel Tasarım

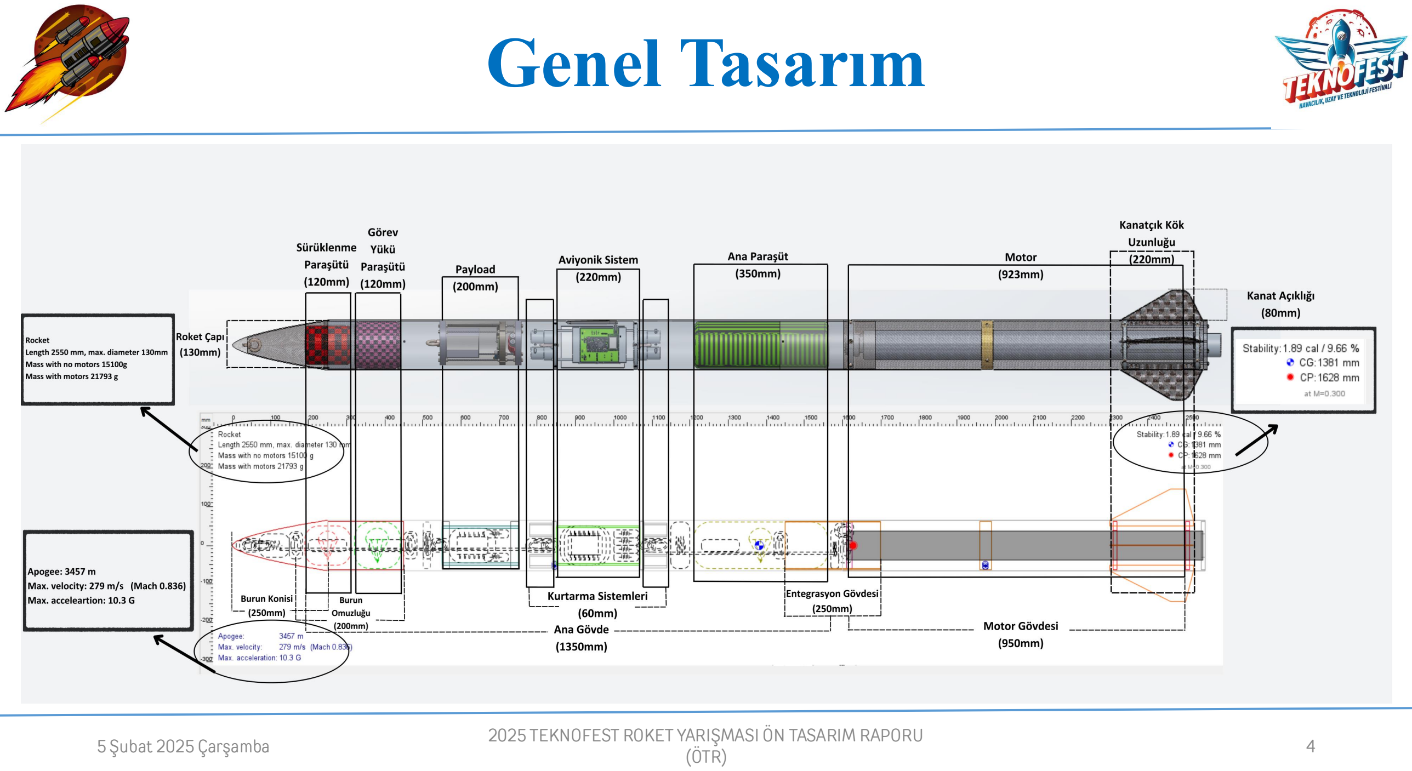
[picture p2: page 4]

5 Şubat 2025 Çarşamba | 4

### 2025 TEKNOFEST ROKET YARIŞMASI ÖN TASARIM RAPORU

1 | 4

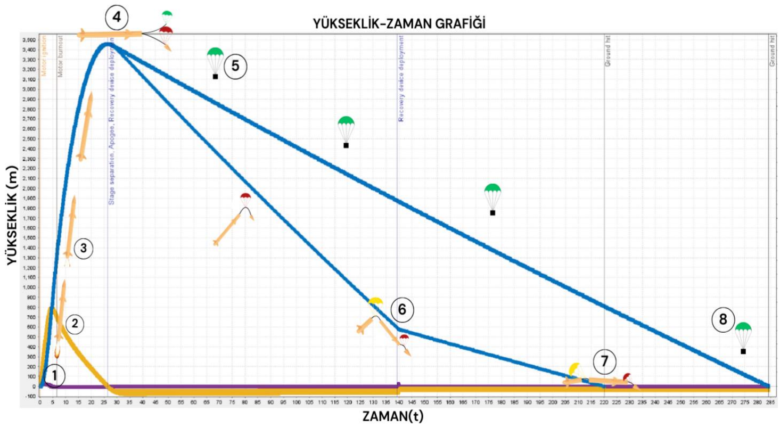
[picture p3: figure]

5 Şubat 2025 Çarşamba | 5

# Operasyon Konsepti (CONOPS)

### 2025 TEKNOFEST ROKET YARIŞMASI ÖN TASARIM RAPORU

| | Zaman (s) | İrtifa (m) | Hız (m/s)
1 | Fırlatma | 0 s | 0 m | 0 m/s
2 | Rampa Tepesi | 0,4 s | 6 m | 32 m/s
3 | Burn Out | 6,5 s | 1296 m | 248 m/s
4 | Apogee* | 26,4 s | 3457 m | 0 m/s
5 | Görev yükünün Ayrılışı | 26,4 s | 3457 m | 0 m/s
6 | Ana Paraşütün Açılması | 163,3 s | 600 m | 26,6 m/s
7 | Roketin Yere İnişi | 246 s | 0 m | 7,53 m/s
8 | Faydalı Yükün Yere İnmesi | 384.7 s | 0 m | 10,3 m/s

# Uçuş Benzetim Raporu (UBR)

5 Şubat 2025 Çarşamba | 6
- Uçuş Benzetim Raporu ek olarak gönderilmiştir.

### 2025 TEKNOFEST ROKET YARIŞMASI ÖN TASARIM RAPORU

- Roketin tüm parçaları ürün ağacı mantığında yansıdaki örneğe uygun olarak “excel” formatında hazırlanarak ayrı bir dosya halinde sisteme yüklenmiştir.

# Kütle Bütçesi

5 Şubat 2025 Çarşamba | 7

## Örnek Kütle Bütçesi

### 2025 TEKNOFEST ROKET YARIŞMASI ÖN TASARIM RAPORU

1 | 7

# Roket Alt Sistem Detayları

5 Şubat 2025 Çarşamba | 8

### 2025 TEKNOFEST ROKET YARIŞMASI ÖN TASARIM RAPORU

# Burun Konisi – Detay

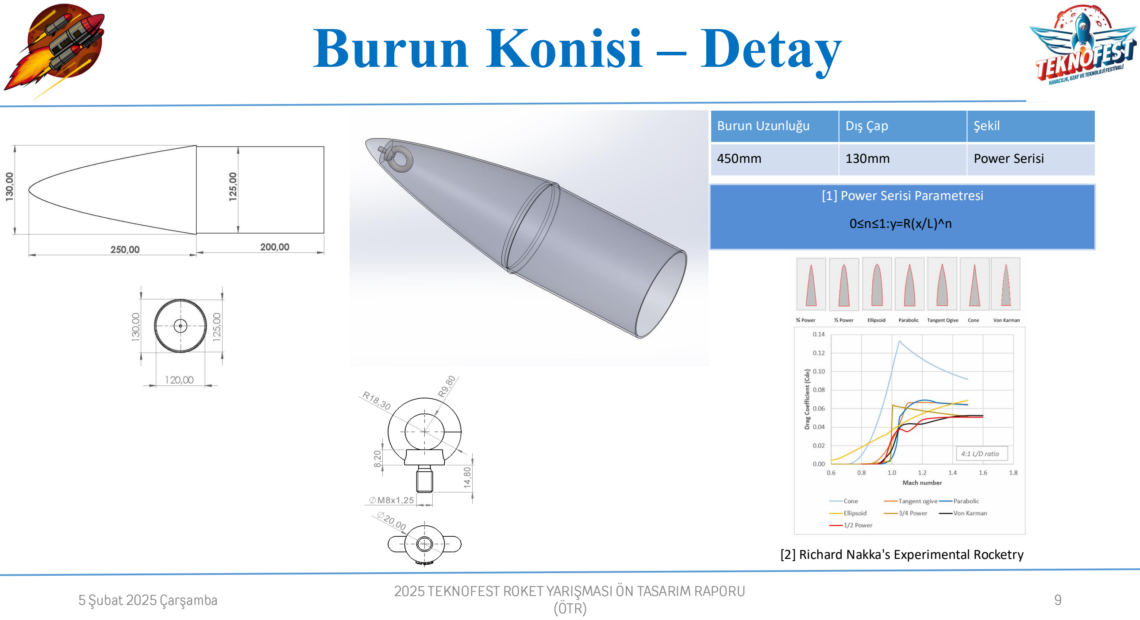
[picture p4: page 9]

5 Şubat 2025 Çarşamba | 9

### 2025 TEKNOFEST ROKET YARIŞMASI ÖN TASARIM RAPORU

Burun Uzunluğu | Dış Çap | Şekil
450mm | 130mm | Power Serisi
[1] Power Serisi Parametresi

0≤n≤1:y=R(x/L)^n

1

[2] Richard Nakka's Experimental Rocketry

# Burun Konisi – Detay

Burun Konisi Şekli Getir/Götür Analizi Tablosu

Özellik | Seçenek 1 | Seçenek 2 | Getir/Götür Analizi Açıklaması
Unsur | Avantaj | Dezavantaj | Unsur | Avantaj | Dezavantaj
Tasarım/Çalışma Prensibi | Power Serisi Burun Konisi | Aerodinamik sürtünmeyi minimize ederek daha verimli uçuş sağlar. | Üretim sürecinde hassas ölçüm ve işçilik gerektirir. | Ogive | Aerodinamik sürtünmeyi minimize ederek yüksek hızlarda verim sağlar. | Sivri uç kısmını üretmek zordur. | Yapılan literatür taramasında sesaltı uçuşlar için her iki şeklin de benzer aerodinamik özelliklerde olduğu görülmüştür. Bu nedenle üretimi daha kolay olduğu için Power Serisi tercih edilmiştir.
Malzeme | Fiberglass | Hafif ve yüksek mukavemetli bir malzemedir. Dielektrik sabiti düşüktür. 1 | Darbelere karşı metal kadar dayanıklı değildir, kırılgan olabilir | Alüminyum 6061 T6 | Yüksek mukavemet-ağırlık oranı: Hafif olmasına rağmen oldukça dayanıklıdır. | Genleşme katsayısı yüksektir. Sıcaklık değişimlerinde yüksek genleşme, büzülme gösterir. Dielektrik sabiti yüksektir. | Burun konisi tasarımında Alüminyum kullanımı dayanım sunar ancak fiberglassa göre daha yüksek yoğunluğa ve genleşme katsayısına sahiptir. Fiberglass,düşük yoğunluk ve darbelere karşı dayanıklılık sunarken aynı zamanda düşük genleşme ve yüksek sinyal geçirgenliği sunar. Bununla birlikte fiberglass alümiyuma göre daha düşük bir maliyet sunar. Bu sebeplerle Fiberglass malzeme tercih edilmiştir.
Üretim Yöntemi | Elle Yatırma | Düşük maliyetli ekipman: Karmaşık makineler gerektirmez, basit el aletleriyle yapılabilir. | İş gücü yoğun: Uzun süren ve dikkat isteyen bir süreçtir, zaman alır. | Talaşlı İmalat | Hassas üretime olanak sağlar. | Maliyetli bir üretimdir. | Elle yatırma üretim yöntemi özel makineler, programlama bilgisi gerektirmez,basit el aletleriyle yapılır. Fakat Talaşlı İmalat CNC veya Torna tezgahlarında yapılır ve bu sebeple maaliyetli bir yöntemdir. Maliyet göz önüne alınarak elle yatırma yöntemi tercih edilmiştir.
5 Şubat 2025 Çarşamba | 10 2025 TEKNOFEST ROKET YARIŞMASI ÖN TASARIM RAPORU

# Kanatçık – Detay

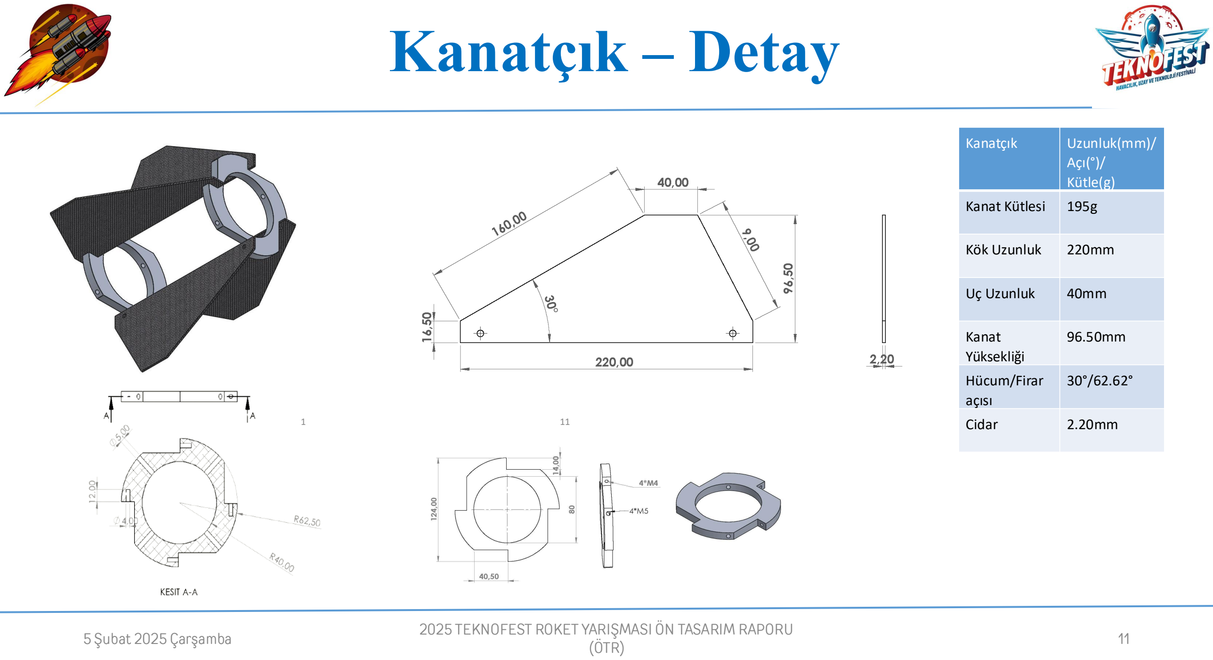
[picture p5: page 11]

5 Şubat 2025 Çarşamba | 11 2025 TEKNOFEST ROKET YARIŞMASI ÖN TASARIM RAPORU
Kanatçık | Uzunluk(mm)/ Açı(°)/ Kütle(g)
Kanat Kütlesi | 195g
Kök Uzunluk | 220mm
Uç Uzunluk | 40mm
Kanat Yüksekliği | 96.50mm
Hücum/Firar açısı | 30°/62.62°
1 | 11 | Cidar | 2.20mm

# Kanatçık – Detay

Kanatçık Getir/Götür Analizi Tablosu

Özellik | Seçenek 1 | Seçenek 2 | Getir/Götür Analizi Açıklaması
Unsur | Avantaj | Dezavantaj | Unsur | Avantaj | Dezavantaj
Tasarım/Ç alışma Prensibi | Civatalı Montajlı Kanatçık | Taşımada kolaylık sağlar. Hasar görmesi durumunda değiştirmesi maaliyetsiz ve kolaydır. | Montaj Zorluğu: Doğru hizalama ve sabitleme için hassas montaj gerektirir. Nispeten ağırdır. | Yapıştırma Montajlı Kanatçık | Merkezlemesi kolaydır. Hafiflik sağlar. | İlk üretim esnasında hassas işçilik gerektirir. Yapılan hatanın telafisi çok zor ve maaliyetlidir. Hasar alması durumunda değiştirilmesi çok zordur. | Cıvatalı Montajlı Kanatçık her ne kadar ek bir ağırlık ve fazla montaj elemanı gerektirse de üretimde, hasar alma durumunda ve taşıma esnasında avantajlar sağladığı için tercih edilmiştir.
Malzeme | Karbon fiber | Korozyona uğramaz, paslanmaz ve kimyasal maddelere karşı 1 dirençlidir. Hafif ve dayanıklıdır. | Yüksek Maliyet: Üretimi pahalıdır ve işleme süreci maliyetlidir. | Fiberglass | Korozyona uğramaz, paslanmaz ve kimyasal maddelere karşı dirençlidir. Ucuzdur. | Karbon fibere göre daha düşük mukavemet ve daha yüksek özkütleye sahiptir. | Fiberglass karbon fibere göre daha kolay ulaşılabilir. Ancak karbon fiberin mukavemeti fiberglassa göre daha yüksek olup çatlamaya ve kırılmaya karşı daha iyi direnç gösterir. Ayrıca karbon fiber daha hafiftir. Kanatçık konumu gereği darbe almaya müsaittir ve kırılma direnci önemli bir parametredir. Dayanım ve hafiflik gibi etmenler nedeniyle karbonfiber kanatçık tercih edilmiştir.
Üretim Yöntemi | Elle Yatırma+Talaşlı İmalat | Tasarım Esnekliği: Elle yatırma ile karmaşık ve özel şekiller oluşturulabilir, talaşlı imalatla hassas son işlemler yapılabilir. | Üretim kalitesi üretimden üretime değişkenlik gösterebilir. | Hazır alım | Standart kalitede hazır ürün alınması kalite sağlar. | Maliyeti yüksektir ve üretim yöntemi önem arz ettiği için kalite kontrol sağlanması zordur. | Hazır ürün alınması daha kolay bir seçenek olsa da üretimde kalitenin kontrol edilebilmesi ve maliyet gibi sebeplerden dolayı Elle Yatırma + Talaşlı imalat tercih edilmiştir.
5 Şubat 2025 Çarşamba | 2025 TEKNOFEST ROKET YARIŞMASI ÖN TASARIM RAPORU
12

# Gövde ve Entegrasyon Parçaları (YAPISAL) Mekanik Görünüm

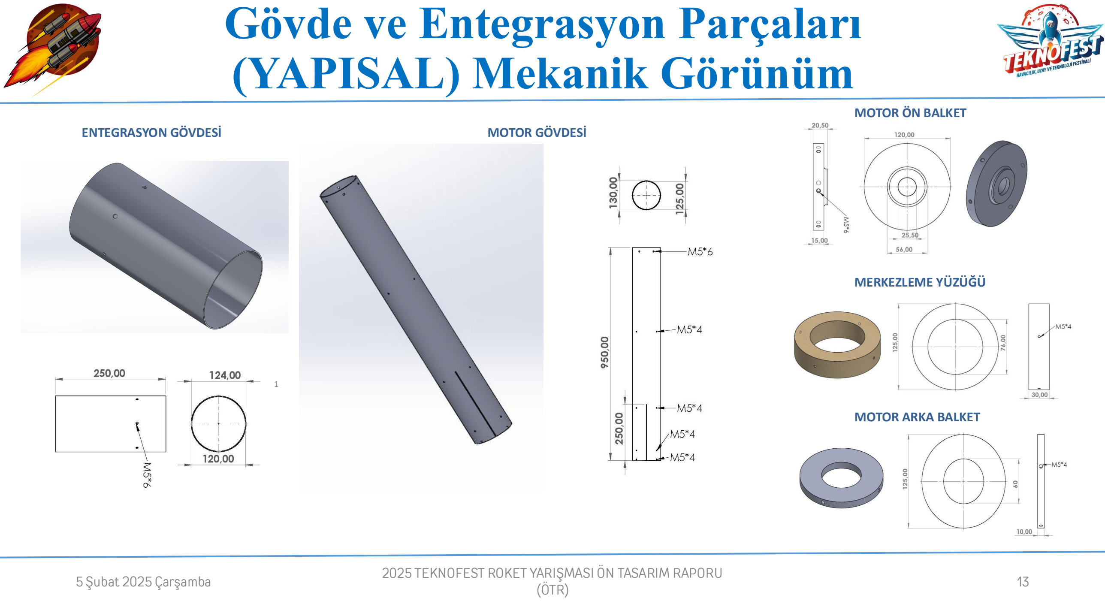
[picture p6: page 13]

5 Şubat 2025 Çarşamba | 13 2025 TEKNOFEST ROKET YARIŞMASI ÖN TASARIM RAPORU
ENTEGRASYON GÖVDESİ | MOTOR GÖVDESİ

MOTOR ÖN BALKET

MOTOR ARKA BALKET

MERKEZLEME YÜZÜĞÜ

1

# Gövde ve Entegrasyon Parçaları (YAPISAL) Mekanik Görünüm

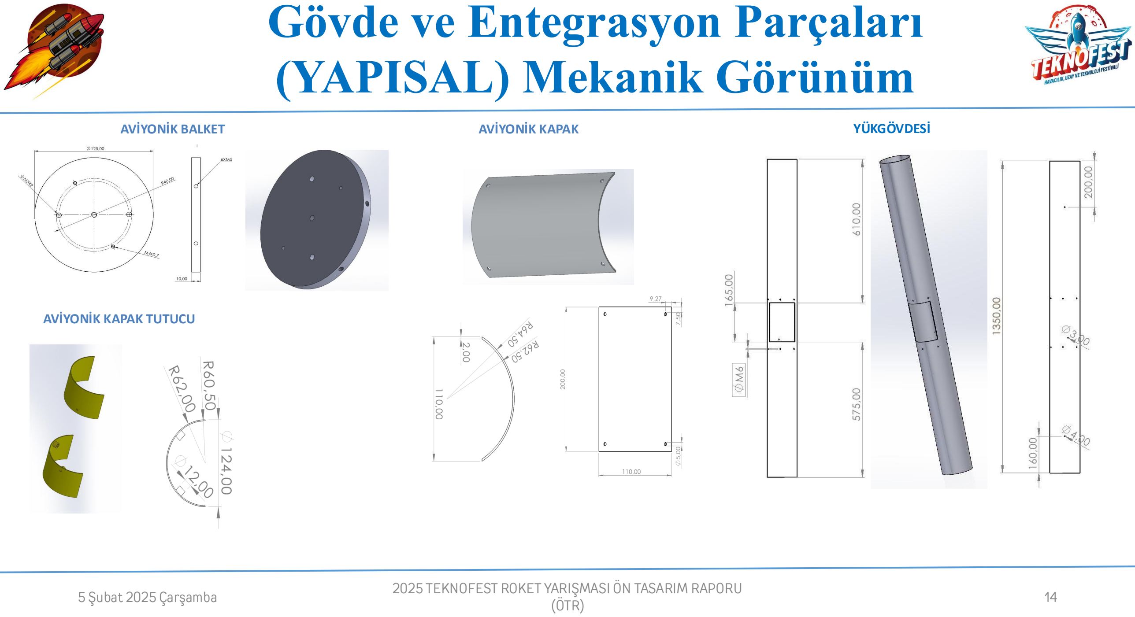
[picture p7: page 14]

AVİYONİK BALKET

AVİYONİK KAPAK TUTUCU

AVİYONİK KAPAK | YÜKGÖVDESİ

### 2025 TEKNOFEST ROKET YARIŞMASI ÖN TASARIM RAPORU

(ÖTR) 5 Şubat 2025 Çarşamba | 14

# Gövde ve Entegrasyon Parçaları (YAPISAL) Mekanik Görünüm

Gövde ve Entegrasyon Parçaları Getir/Götür Analizi Tablosu

Özellik | Seçenek 1 | Seçenek 2 | Getir/Götür Analizi Açıklaması
Unsur | Avantaj | Dezavantaj | Unsur | Avantaj | Dezavantaj
Malzeme | Fiberglass | Sinyal geçirgenliği iyidir ve ucuzdur. | Özkütlesi daha yüksektir. Mukavemeti daha düşüktür. | Karbonfiber | Yüksek mukavemetlidir. Özkütlesi düşüktür. | Sinyal geçirgenliği kötüdür. Pahalıdır. | Sinyal geçirgenliğinin çok önemli olduğu Yük Gövdesi için kütle dezavantajına rağmen fiberglass malzeme seçilmiştir. Gerekli dayanımı sağlayıp sağlamayacağı yapısal analizlerle tespit edilecektir. Motor gövdesi için sinyal geçirgenliği önemli bir parametre olmadığı için maliyet dezavantajına rağmen mukavemet/kütle oranı daha yüksek olan karbon fiber malzeme tercih edilmiştir.
Üretim Yöntemi | [3] Erkek Kalıba Elle Yatırma | Düşük maliyet. Üretimi için kompleks makine ihtiyacı yoktur. | Yüzeyde pürüzler veya istenmeyen izler olabilir ek işlem gerekebilir. | [4] Filament Sarma Yöntemi | Yüzey kalitesi daha iyidir. Filament/reçine oranı daha yüksek. | Maliyeti yüksek. Üretimi için kompleks filament sargı makinesine ihtiyaç duyulur. | Erkek kalıba elle yatırma makineli işlemlere göre daha düşük maliyetlidir ve daha az ekipman gereksinimi vardır ancak elle yapılan işlemler otomatik üretim yöntemlerine göre daha yavaş ve insan hatasına açık bir süreçtir. Maliyet ve üretim kolaylığı göz önüne alınarak Erkek Kalıba Elle Yatırma yöntemi tercih edilmiştir.

### 2025 TEKNOFEST ROKET YARIŞMASI ÖN TASARIM RAPORU

(ÖTR) 5 Şubat 2025 Çarşamba | 15

# Motor Bölümü Mekanik Görünüm & Detay

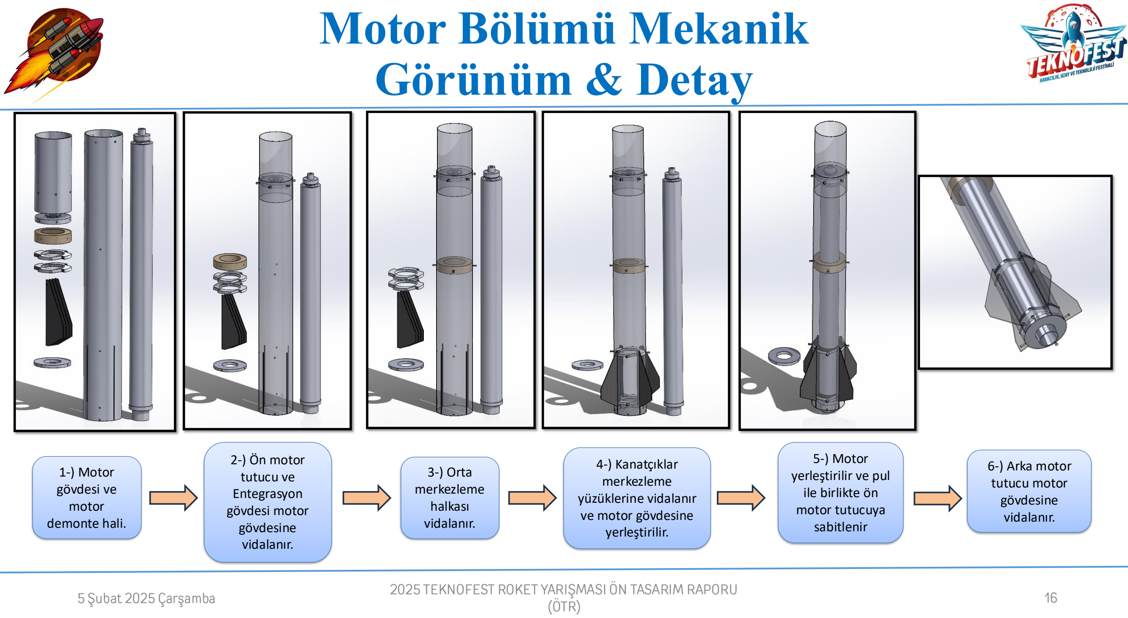
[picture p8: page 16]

5 Şubat 2025 Çarşamba | 16 2025 TEKNOFEST ROKET YARIŞMASI ÖN TASARIM RAPORU

1-) Motor
gövdesi ve
motor
demonte hali.

2-) Ön motor
tutucu ve
Entegrasyon
gövdesi motor
gövdesine
vidalanır.

3-) Orta
merkezleme
halkası
vidalanır.

4-) Kanatçıklar
merkezleme
yüzüklerine vidalanır
ve motor gövdesine
yerleştirilir.

5-) Motor
yerleştirilir ve pul
ile birlikte ön
motor tutucuya
sabitlenir

6-) Arka motor
tutucu motor
gövdesine
vidalanır.

1

# Motor Bölümü Mekanik Görünüm & Detay

5 Şubat 2025 Çarşamba | 2025 TEKNOFEST ROKET YARIŞMASI ÖN TASARIM RAPORU

Motor Montaj Stratejisi Getir/Götür Analizi Tablosu

Özellik | Seçenek 1 | Seçenek 2 | Getir/Götür Analizi Açıklaması
Unsur | Avantaj | Dezavantaj | Unsur | Avantaj | Dezavantaj

Montaj Stratejileri

Önce ön motor
balketi̇ve
entegrasyon
gövdesi̇
montajlanma

Motorun
yerleşti̇ri̇lmesi̇
esnasında
motorun ön
motor balketi̇
yüzeyi̇ne paralel
temas etmesi̇ve
vi̇dalama
esnasında vi̇danın
di̇ş kaçırmadan
daha rahat
sıkılması

Entegrasyon
gövdesi̇
uzunluğu
sebebi̇yle
motor vi̇dasına
eri̇şi̇mi̇n
zorlaşması

Önce arka
motor kapağı
montajı

Ön motor
balketi̇ne motor
vi̇dalanırken
entegrasyon
gövdesi̇ni̇n motor
vi̇dasını sıkmaya
engel olması

Motorun arka
motor kapağına
yaslanmasi
sebebi̇yle ön
motor balketi̇ne
vi̇dalanırken
balket i̇le motor
gövdesi̇
deli̇kleri̇ni̇n denk
gelmemesi̇
sebebi̇yle motoru
döndürme
i̇hti̇yacı
doğurması

Tasarımımıza göre ön motor balketi̇ni̇n önce montajlanması motorun montajı esnasında daha kolay vi̇dalanması sebebi̇yle ve olası vi̇da deli̇kleri̇ni̇n denk gelmemesi̇durumunda motoru kısıtlı alan i̇çeri̇si̇nde döndürmek zorunda kalmamız sebebi̇yle ön motor balketi̇ni̇önce vi̇dalamanın daha avantajlı olduğu sonucuna varılmıştır.

1 | 17

17

# Kurtarma Sistemi – Paraşüt Açma Sistemi

5 Şubat 2025 Çarşamba | 18 2025 TEKNOFEST ROKET YARIŞMASI ÖN TASARIM RAPORU

Ayrılma Sistemi Getir/Götür Analizi Tablosu

Özellik | Seçenek 1 | Seçenek 2 | Getir/Götür Analizi Açıklaması
Unsur | Avantaj | Dezavantaj | Unsur | Avantaj | Dezavantaj
Tasarım/Çalışma Prensibi | Piroteknik Ayrılma Sistemi | Piroteknik ayrılma basit ve hafif bir yöntemdir. Düşük ağırlıklı ve yüksek basınçlı bir sistemdir. | Piroteknik kimyasalın patlaması neticesinde açığa çıkan ateş aviyonik ve kurtarma sistemi için yangın tehlikesi yaratır. | CO2 Tüplü Ayrılma Sistemi | Yüksek basınç sağlar. Basınçla birlikte ateş ve ısı açığa çıkmadığı için yangın ve aviyoniklerin zarar görmesi riski düşüktür. | CO2 Tüplerinin kullanılması için tasarlanacak mekanik sistem ağır ve karmaşıktır. | Piroteknik ayrılma sistemleri içerisinde patlayıcı maddeler kullanıldığı için yüksek güvenlik riskleri taşır ancak CO2 Tüplü ayrılma sistemleri teknik sorun çıkarabilecek birden fazla mekanik aksam vardır. Daha hızlı ve yüksek enerjili ayrılma ve konrtollü patlama gereksinimlerinde piroteknik ayrılma sistemi daha iyi performans sunar. Bu nedenle piroteknik ayrılma sistemi tercih edilmiştir.
Aviyonik sistem Apogee'yi algılar. | Mikroişlemci MOSFET modülüne sinyal gönderir. | MOSFET modülü eyleyiciyi ateşler.
Sürüklenme paraşütü ve görev yükü fırlayan burun konisinden ayrılır. | Ateşlenen piroteknik sistem ayrılmayı
gerçekleştirir.
Aviyonik sistem 600 metre irtifaya indiğini algılar. | Mikroişlemci MOSFET modülüne sinyal gönderir | MOSFET modülü eyleyici
ateşler

Ana paraşüt entegrasyon gövdesinden ayrılır

# Kurtarma Sistemi – Paraşüt Açma Sistemi

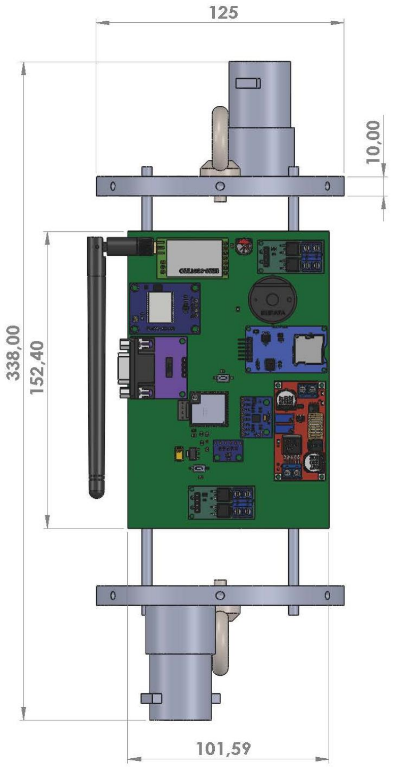
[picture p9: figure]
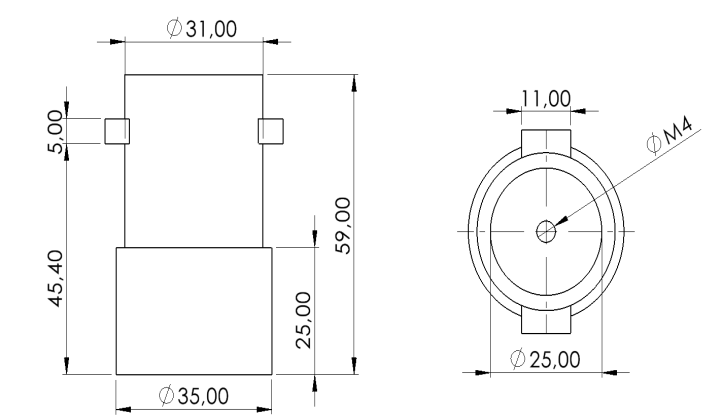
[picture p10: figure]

5 Şubat 2025 Çarşamba | 19 2025 TEKNOFEST ROKET YARIŞMASI ÖN TASARIM RAPORU
KURTARMA SİSTEMİ MONTAJ | PİROTEKNİK KAPSÜL | Kurtarma
Alt Sistemi | Görevi
Mikroişlemci | Sensörlerden aldığı verileri anlamlandırarak gerekli yerlerde ayrılma emirlerini verir.
MOSFET Modülü | Mikroişlemciden aldığı tetikleme sinyali ile Piroteknik Eyleyiciyi aktif eder.
Piroteknik Eyleyici | Gelen enerji doğrultusunda Piroteknik Kapsülü ateşler.
Piroteknik Kapsül | Piroteknik Eyleyiciden gelen ateşle patlayarak basınç yaratarak ayrılmayı sağlar.
Mapa | Yapısal elemanları kurtarma sistemine bağlar.
Şok Kordonu | Paraşüt açılmasından doğan ani yükleri esnek yapısı ve uzun boyu sayesinde sönümleyip bağlantı elemanlarına zarar gelmesini engelleyen paraşüt ve roket arasındaki bağlantıyı yapan temel elemandır.
Karabina | Şok kordonları, mapalar ve fırdöndüler arasındaki bağlantıları sağlayan elemandır.
Fırdöndü | Paraşüt iplerinin dolaşmasını engeller.
KARABİNA (8mm) | FIRDÖNDÜ (M8)

Kurtarma Sisteminin toplam hacmi 0,00883 m^3'tür.

MAPA (M8)

# Sıcak Gaz Üreteci Gereksinimleri

5 Şubat 2025 Çarşamba | 20
Ayrılma | Basınçlandırılacak Hacim Çapı (mm) | Basınçlandırılacak Hacim (m^3) | Ulaşılmak İstenen Basınç (Bar)
1. Ayrılma | 125 | 1.84×10^-3 | 1.24 Bar
2. Ayrılma (Varsa) | 125 | 3.91x10^-3 | 1.4 Bar

### 2025 TEKNOFEST ROKET YARIŞMASI ÖN TASARIM RAPORU

Şartnamenin ilgili kısmı göz önüne alınarak, piroteknik kapsülün yarışma komitesi tarafından verileceği ve montajının alanda yapılacağı düşünülerek sistem tasarlanmıştır.

Basınçlandırılacak hacim için πr^2 h formülü kullanılmıştır.

1. ayrılma için basınçlandırılacak hacim hesabı; π〖 x 0.0625〗^2 x 0.23=0.00282 m^3
2. ayrılma için basınçlandırılacak hacim hesabı; π x 〖0.0625〗^2 x 0,37=0.00454 m^3

Gerekli olan basınç Force=Pressure X Area ve FAyrılma= Fdış + Fs + W formülüyle hesaplanmıştır. [5]

1. ayrılma için basınçlandırılacak kuvvet hesabı; 12272mm^2 X 0,124 MPa = 1522 N
2. ayrılma için basınçlandırılacak kuvvet hesabı; 12272 mm^2 x 0,14 MPa = 1718 N

# Kurtarma Sistemi – Paraşütler -1

5 Şubat 2025 Çarşamba | 21 2025 TEKNOFEST ROKET YARIŞMASI ÖN TASARIM RAPORU
- Kurtarma sistemimizde ana paraşüt, görev yükü paraşütü ve sürükleme paraşütü olmak üzere toplamda 3 adet paraşüt olacaktır. Kullanılacak paraşütlerin hepsi kubbe yapıya sahiptir. Paraşütlerin üst kısmında, salınımı azaltmak için paraşüt çaplarının %15'i çapında kubbe deliği olacaktır. 3 paraşütün kaplayacağı toplam hacim 584 cm^3’tür.
- Paraşütlerde kullanılacak malzeme dayanıklılığı ve yırtılmaz özelliği nedeniyle ripstop naylon, kullanılacak paraşüt iplerini malzemesi ise dayanıklılık ve esneklik özellikleri sebebiyle polyester olarak seçilmiştir. Paraşütlerdeki kubbe deliklerinin çapları salınımı engellemek için paraşüt çaplarının %15’i olacak şekilde hesaplanmıştır. Paraşüt iplerinin boyu ise paraşüt çaplarının 1.25-2.25 katı olacak şekilde belirlenmiştir. [6]
- Sıcak gaz üretici (barut) kullandığından paraşütlerin yanma ile deforme olmasına karşı yanmaz kumaş kullanılacaktır.
- Roket ve Görev Yükü tamamen ayrı şekilde 2 parça olarak Apogee noktasında kurtarılacaktır.
- Apogee noktasında Sürüklenme ve Görev yükü paraşütü açılacak ve 600-400 m irtifaya kadar Roket sürüklenme paraşütüyle düşecektir. Roket, 600 m irtifanın altına indikten sonra Ana UKB tarafından gönderilen sinyalle Ana Paraşüt açılır ve roket kurtarılır.
- Roket ve Görev Yükü üzerinde bulunan GPS sayesinde konum verileri gerçek zamanlı olarak yer istasyonuna gönderilecek ve inişten sonra bu konum tespit edilerek roketin kurtarılması tamamlanacaktır.
- Rokete ve Görev Yüküne ait tüm bileşenlerin yeniden kullanılabilir şekilde kurtarılması amaçlanmaktadır.
Paraşüt Tipi | Renk | Boyutlar | Paraşüt İpi Uzunluğu (m) | Kubbe Deliği Çapı (m) | Parça (Dilim) Sayısı | Kütle (g)
Açık Çap (m) | Kapalı Uzunluk (m)
Faydalı Yük Paraşütü | Yeşil | 1 m | 0.12m | 1 m | 0.12 m | 8 | 107 g
Sürüklenme Paraşütü | Kırmızı | 0.9 m | 0.12 m | 1 m | 0.135 m | 8 | 97 g
Ana Paraşüt | Turuncu | 2.5 m | 0.35 m | 3 m | 0.375 m | 8 | 521 g

# Kurtarma Sistemi – Paraşütler -1

5 Şubat 2025 Çarşamba | 22 2025 TEKNOFEST ROKET YARIŞMASI ÖN TASARIM RAPORU
KURTARILACAK UNSURLAR | SENSÖRLER ve MİKROİŞLEMCİLER | GÖREVLERİ | HANGİ AŞAMADA KURTARILACAK
| DHT22 | Havadaki nem verisini ölçer. | Görev yüküyle beraber Apogee'de kurtarılır.
| BMP280 | Basınç verilerini ölçer. | Görev yüküyle beraber Apogee'de kurtarılır.
| NEO-6M | Konum verisini elde eder. | Görev yüküyle beraber Apogee'de kurtarılır.
| Lora E22 900T22D | Verilerin yer istasyonuna aktarılmasını sağlar. | Görev yüküyle beraber Apogee'de kurtarılır.
| ESP32 S3 WROOM 1U | Sensörlerden gelen verileri işler ve yer istasyonuna gönderir, bilimsel görevin gerçekleştirilmesini sağlar. | Görev yüküyle beraber Apogee'de kurtarılır.
| ESP32 S3 WROOM 1U | Sensörlerden aldığı verilerle roketin kurtarılmasını sağlar. Sensörlerden aldığı verileri Lora aracılığıyla yer istasyonuna iletir. | Roketle beraber 2. açılmada kurtarılacak.
| NEO-6M | Konum verisini elde eder. | Roketle beraber 2. açılmada kurtarılacak.
| BMP280 | Basınç verilerini ölçer. | Roketle beraber 2. açılmada kurtarılacak.
| MPU6050 | İvme ve açı verilerini ölçer. | Roketle beraber 2. açılmada kurtarılacak.
| Lora E22 900T22D | Verilerin yer istasyonuna aktarılmasını sağlar. | Roketle beraber 2. açılmada kurtarılacak.
RRC3 | Uçuşu yöneten ticari UKB'dir. | Roketle beraber 2. açılmada kurtarılacak.

GÖREV YÜKÜ

ROKET

# Kurtarma Sistemi – Paraşütler -2

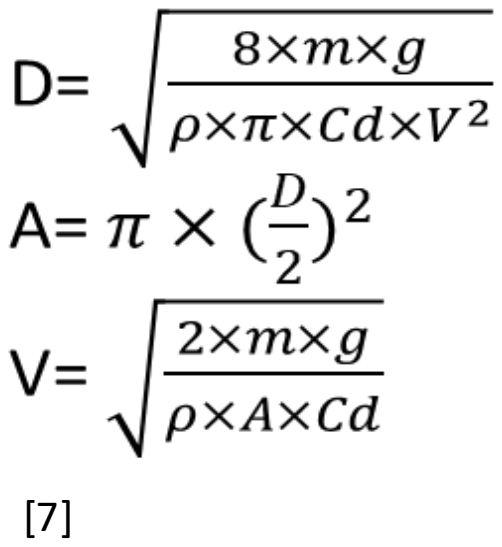
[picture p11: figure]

5 Şubat 2025 Çarşamba | 23 2025 TEKNOFEST ROKET YARIŞMASI ÖN TASARIM RAPORU
Paraşüt Sistemi | Paraşüt Alanı (m^2) | Paraşüt Sisteminin Taşıyacağı Kütle (kg) | Paraşüt Sürüklenme Katsayısı | Düşüş Hızı (m/s)
Faydalı Yük Paraşütü | 0.785 | 4.300 kg | 0.8 | 10.5
Sürüklenme Paraşütü | 0.64 | 13.848 kg | 0.8 | 20.81
Ana Paraşüt | 4.9 | 13.848kg | 0.8 | 7.5

## Paraşüt Çapı

## Paraşüt Alanı

## Paraşüt Hızı

## m= Kütle g= Yer Çekimi(9,81m/s^2) ρ=Havanın Özkütlesi(1.225kg/m^3) Cd=Sürüklenme Katsayısı

Tabloda yer alan verilerden paraşüt alanı ve düşüş hızı verileri yanda yer alan formüllere göre hesaplanmış ve yazılmıştır. Paraşüt sisteminin taşıyacağı kütle bilgileri OpenRocket programından alınmıştır.

Görev yükünün ağırlığı 4100 gram iken, ilgili paraşüt sisteminin taşıyacağı toplam kütle hesaplantımştır.Diğer hesaplamalar da bu mantık kullanılarak yapılmıştır.

# Görev Yükü

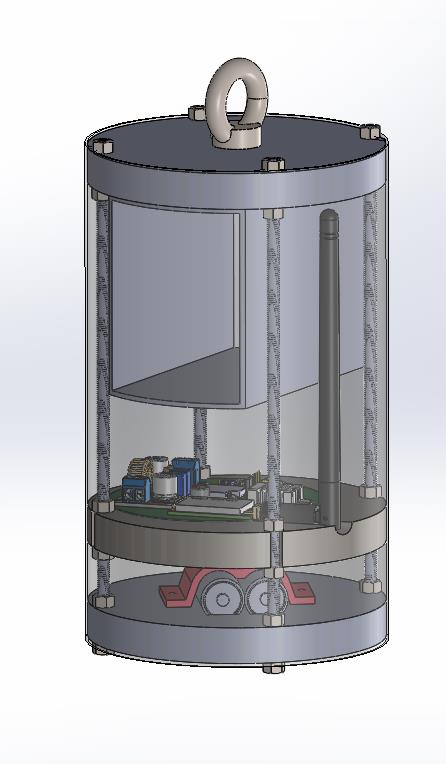
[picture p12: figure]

5 Şubat 2025 Çarşamba | 24 2025 TEKNOFEST ROKET YARIŞMASI ÖN TASARIM RAPORU

Bilimsel Görev Yükümüz içerisinde bulunan higroskopik maddeler (Kuru Buz, Gümüş İyodür) sayesinde bulut

içindeki su buharında kristal çekirdeklenmeler oluşturarak buz kristallerine dönüşmesi ve buz kristallerinin

eriyerek yağmur sularını oluşturması yani Buluta Yağmur Tohumlanma görevini gerçekleştirecektir.

Bulut tohumlama, atmosferdeki bulutlara belirli kimyasal maddeler (genellikle gümüş iyodür) püskürterek

yağış miktarını artırma veya yağışın oluşmasını sağlama işlemidir. Bu işlem, özellikle kuraklık yaşanan

bölgelerde veya su kaynaklarının yetersiz olduğu durumlarda kullanılır.

## Görev Yükü Amacı

# Görev Yükü

25

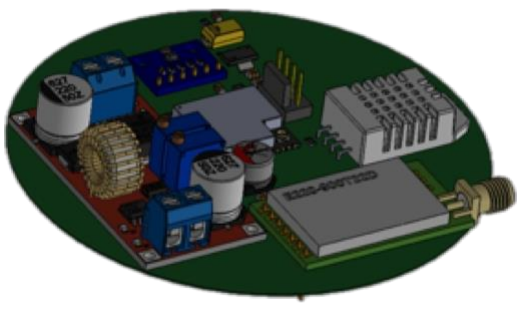
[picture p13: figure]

5 Şubat 2025 Çarşamba | 2025 TEKNOFEST ROKET YARIŞMASI ÖN TASARIM RAPORU

Bilimsel görev yükü, apogee noktasında piroteknik sistemin ateşlenmesiyle birlikte roketin baş kısmından ayrılacaktır. Görev yükünün konumu, üzerinde bulunan GPS sistemi sayesinde takip edilecek ve turuncu renk paraşüt sayesinde kolayca bulunabilecektir. Görev yükünün toplam kütlesi: 4100 gram olacaktır.

BMP280 basınç sensörü, DHT22 nem sensörü ve NEO-6M GPS modülünün verileri Lora E22 900T22D telemetri modülü aracılığıyla 5 Hz frekansla iletilecektir. Veriler, yer istasyonundaki Lora modülüne iletilip, ESP32 S3 WROOM 1U ile çözümlenerek bilgisayara aktarılacaktır. Alınacak veriler:
- Barometrik sensörden basınç ve sıcaklık verisi
- GPS’den konum ve zaman verisi.
- Nem sensöründen nem verisi

Sensör verileri, Kalman filtresinden geçirilerek görev yükündeki mikro kontrolcü tarafından toplanır, microSD karta ve Lora modülüne aktarılır. Ana roketin uçuş kontrol bilgisayarı, apogee noktasında paraşüt salınım mekanizmasını tetikler. MOSFET’ sinyal yollayarak fitil ateşlenir ve görev yükü roketten ayrılır. Barometre, görev yükünün apogee noktasında olduğunu tespit edip paraşüt mekanizmasını devreye sokar. Tüm bu süreçlerde görev yükü roketten bağımsızdır.

Görev Yükü Ayrılması ve Paraşüt Mekanizması Kontrolü

Roket Görev Yükü Tasarımı ve İzleme Sistemi

Görev Yükü Ayrılması ve Takibi

# Aviyonik – Özet

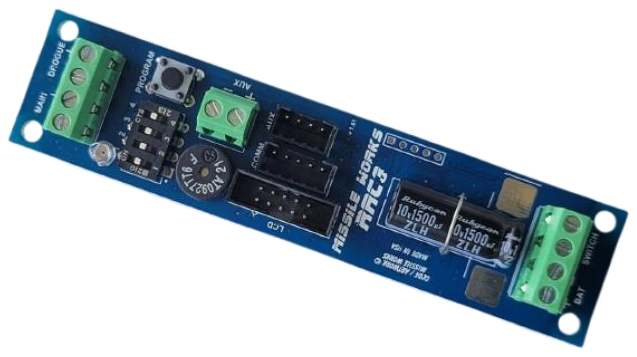
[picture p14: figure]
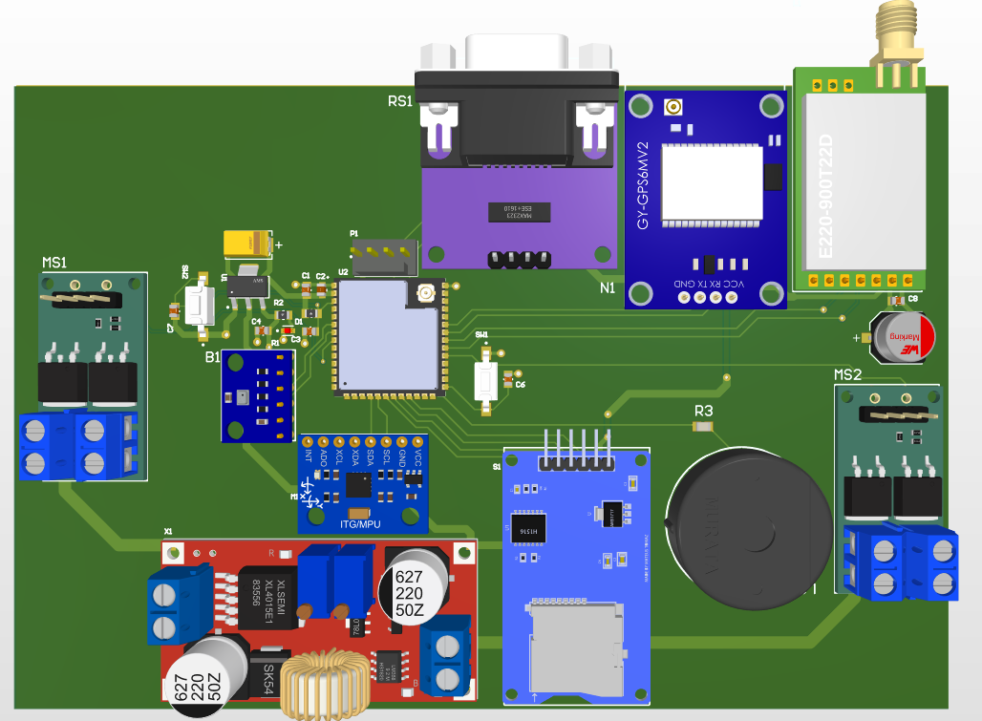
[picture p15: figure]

5 Şubat 2025 Çarşamba | 26 2025 TEKNOFEST ROKET YARIŞMASI ÖN TASARIM RAPORU

Yukarida 3D görüntüsü verilen özgün UKB, içerisinde bulunan çeşitli sensörler ve mikrokontrolcü aracılığıyla roketi uçuş boyunca yönetme ve paraşütleri açma gibi fonksiyonları gerçekleştirecektir. Kartın mikroişlemcisi ESP32 S3 WROOM 1U'dur. IMU sensör olarak MPU6050, basınç ve sıcaklık sensörü olarak BMP280, GPS sensörü olarak NEO 6M, haberleşme için Lora E22 900T22D telemetri modülü ve veri depolama için mikro SD kart modülü kullanılmıştır. Kartta enerji indikatörü olarak buzzer kullanılmıştır. Paraşütlerin açılması, XL4015 voltaj regülatörünün giriş pinlerinden gelen enerji ve mikroişlemciden gelen tetikleme sinyali aracılığıyla MOSFET modüllerinin elektronik fitili ateşlemesiyle gerçekleşecektir.

Kullanımına izin verilen dokuz adet ticari UKB'den biri olan RRC3 Sport Altimeter kartı sadece basınç sensörü kullanıp oldukça başarılı bir şekilde roketin isterlerinde olan paraşüt açma görevlerini gerçekleştirebilmektedir. Yüksek hassasiyetli MS5607 basınç sensörü ve MSP430 serisi mikrokontrolcüsü sayesinde içindeki algoritmayı başarılı şekilde işlemektedir. Bünyesinde GPS ve telemetri modülü olmamasına rağmen üstündeki COMM portu sayesinde bu eksiklik giderilebilmektedir. Kişiselleştirmeye izin veren yapısı sayesinde uçuşun istenilen şekilde yönetilebilmesine olanak sağlamaktadır. Çift ayrılma olanağı sunmaktadır ve açık drenaj MOSFET yapısıyla elektronik ateşleyicilerin bağlandığı konnektörlere enerji aktarımı yapmaktadır. [ 9]

[8 ]

# Aviyonik – Özet

5 Şubat 2025 Çarşamba | 27 2025 TEKNOFEST ROKET YARIŞMASI ÖN TASARIM RAPORU

Benzerlik ve Farklılık Tablosu
Benzerlik | Farklılık
İki sistemde de basınç sensörü bulunmaktadır. | RRC3 Sport Altimeter'ın algoritması yalnızca bünyesindeki basınç sensörüne dayanmaktadır.
İki sistem de 3.7V Lİ-ion pillerle beslenmektedir. | RRC3 Sport Altimeter'da sistem içinde GPS veya telemetri modülü yoktur
İki sistem de çift ayrılma gerçekleştirecek algoritma ihtiva etmektedir. | RRC3 3.5V-10V aralığıında beslenebilirken özgün UKB'nin besleme voltajı 7.4V olmak üzere sabittir. [10]
İki sistem de MOSFET tabanlı bileşenlerle paraşüt açılmalarını gerçekleştirecektir. [11] | RRC3 Sport Altimeter'da bulunan buzzer çok fonksiyonlu iken özün UKB'deki buzzer sadece enerjinin verildiğinin indikatörüdür.
İki sitemde de veri depolama elemanı bulunmaktadır. [12] | RRC3 Sport Altimeter daha bütünleşik bir yapıya sahipken özgün UKB daha modüler bir tasarımdır.

Özgün ve ticari UKB'ler arasında arasında kablolu veya kablosuz herhangi bir bağlantı bulunmamaktadır. Rokette bulunan kurtarma sistemleri şartnamede belirtildiği üzere her iki UKB tarafından yönetilecektir.

# Aviyonik – 1.Sistem Detay/1

5 Şubat 2025 Çarşamba | 28 2025 TEKNOFEST ROKET YARIŞMASI ÖN TASARIM RAPORU
Adı | Kodu | Avantaj | Dezavantaj | Açıklama
İvme ve GYRO Sensörü | MPU6050 | Maliyeti ve güç tüketimi azdır. | Hassasiyeti azdır. | İvme ve jiroskop verisi göndermek.
İvme ve GYRO Sensörü | BNO055 | Sensör Füzyonu içerir. [13] | Maliyeti ve güç tüketimi fazladır. | İvme, jiroskop ve manyetometre verisi göndermek.
Mikro Kontrolcü | STM32F407 | Daha güçlü çevre birimleri ve gelişmiş DSP içerir. | Daha karmaşık geliştirme süreci ve tek çekirdek işlemci | Uçuş bilgisayarının yönetimini sağlar.
Mikro Kontrolcü | ESP32-WROOM-1U | GPIO Matrix [14], çift çekirdek işlemci, az güç tüketimi ve harici bellek desteği. | Pin sayısı azdır. | Uçuş bilgisayarının yönetimini sağlar.
Haberleşme modülü | E22-900T22D | Çok düşük güç tüketimi ile batarya ömrünü uzatır. | Daha düşük veri hızı | Roket ve yer istasyonu arasında veri iletimini sağlamak.

# Aviyonik – 1.Sistem Detay/1

5 Şubat 2025 Çarşamba | 29 2025 TEKNOFEST ROKET YARIŞMASI ÖN TASARIM RAPORU
Adı | Kodu | Avantaj | Dezavantaj | Açıklama
Haberleşme modülü | XBee SX 900 | DigiMesh desteği ile daha esnek ağ yapısı kurabilir. [15] | Daha fazla güç tüketir. | Roket ve yer istasyonu arasında veri iletimini sağlamak.
GPS | NEO-6M | Düşük güç modu ve düşük maliyet | Daha fazla yapılandırma ve ayar gerekir | Konum takibi sağlar, yönlendirmeye yardımcı olur.
GPS | Adafruit Ultimate GPS | Daha stabil, hızlı bağlantı ve Kolay entegrasyon | Maliyeti yüksektir. | Konum takibi sağlar, yönlendirmeye yardımcı olur.
Basınç ve sıcaklık sensörü | DSP310 | Yüksek tutarlılık ve hassasiyet oranı vardır. Dahili FIFO bulunur. [16] | Yaygın bulunmaz. | Basınç verisi kullanarak irtifa hesaplamak.
Basınç ve sıcaklık sensörü | BMP280 | Maliyeti az ve daha yaygın bulunur | Daha az konfigürasyon seçeneği vardır ve daha gürültülüdür. | Basınç verisi kullanarak irtifa hesaplamak.

# Aviyonik – 1.Sistem Detay/2

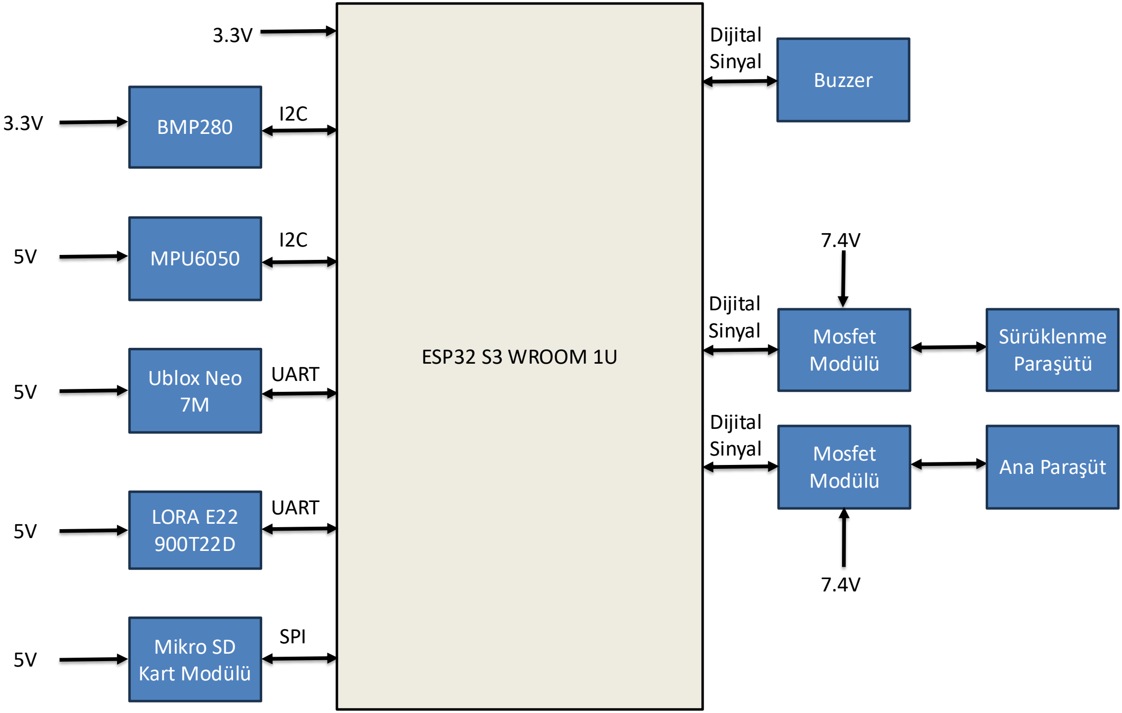
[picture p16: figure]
ESP32 S3 WROOM 1U; LORA E22 900T22D; BMP280; MPU6050; Mikro SD Kart Modülü; Buzzer; Ublox Neo 7M; Mosfet Modülü; Sürüklenme Paraşütü; Ana Paraşüt; UART; SPI; Dijital Sinyal

5 Şubat 2025 Çarşamba | 30 2025 TEKNOFEST ROKET YARIŞMASI ÖN TASARIM RAPORU

2S2P 3.7V Li-ion Pil

Mekanik Anahtar

XL4015 Voltaj Regülatörü

AMS1117 Voltaj Regülatörü

7.4V

7.4V

5V

3.3V

Özgün UKB'de bulunan sensörlere ve mikroişlemciye gelen enerji XL4015 ve AMS1117 voltaj regülatörlerinden verilmiştir. Elektronik
fitilleri ateşleyecek olan enerji XL4015 buck dönüştürücünün giriş
pinlerinden sağlanacaktır.

# Aviyonik – 1.Sistem Detay/2

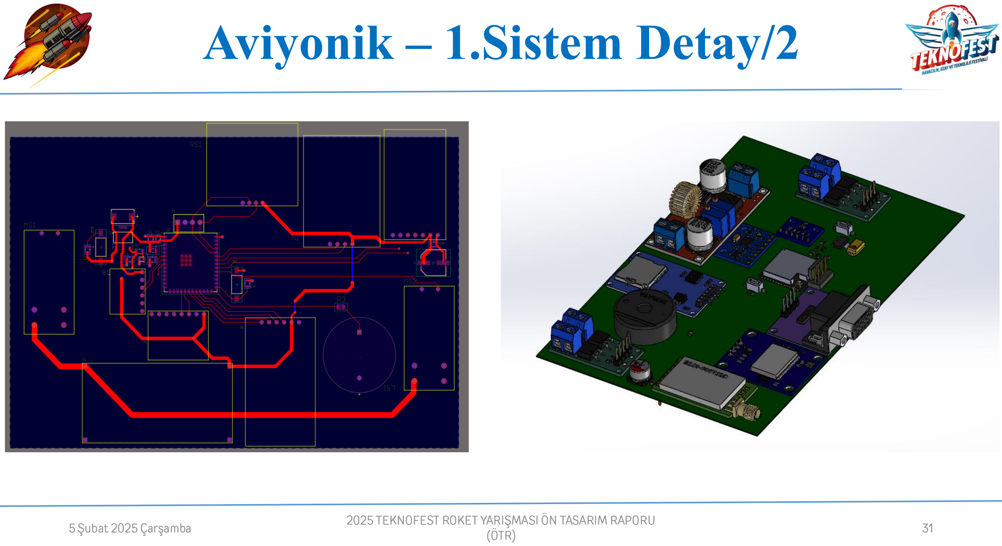
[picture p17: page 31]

5 Şubat 2025 Çarşamba | 31 2025 TEKNOFEST ROKET YARIŞMASI ÖN TASARIM RAPORU

1

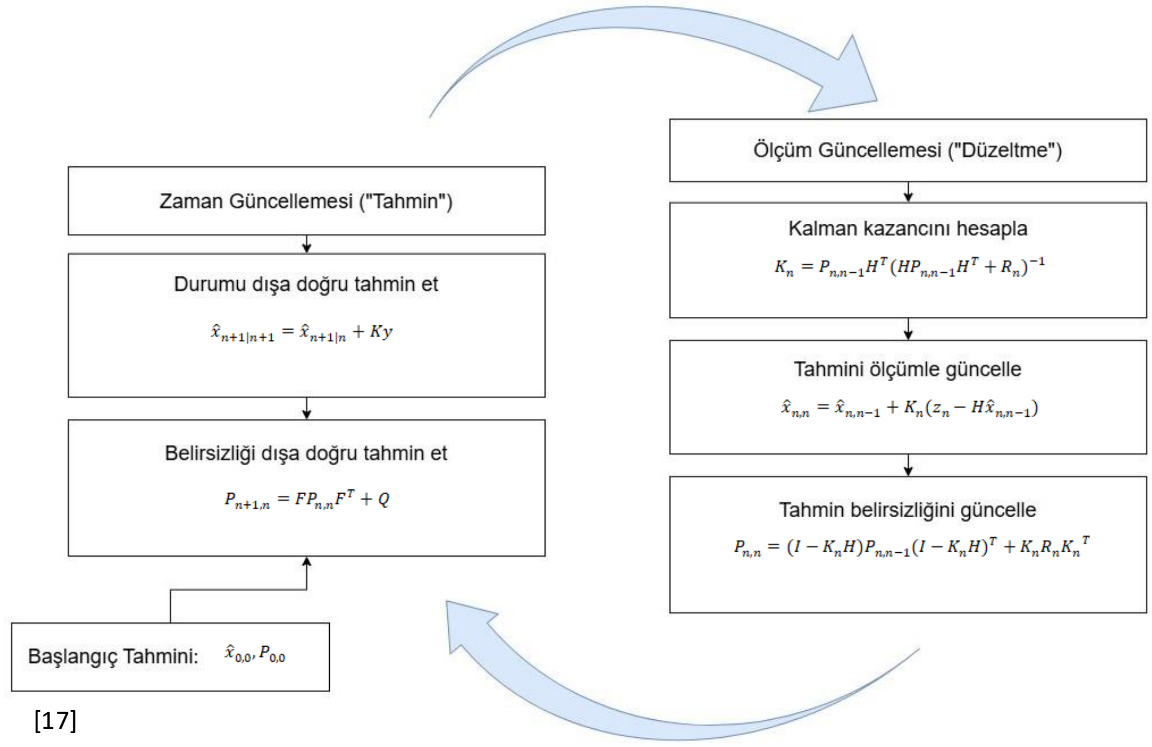
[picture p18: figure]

5 Şubat 2025 Çarşamba | 32

# Aviyonik – 1.Sistem Detay/3

### 2025 TEKNOFEST ROKET YARIŞMASI ÖN TASARIM RAPORU

1 | 32

Kurtarma sistemini tetikleyecek parametreler:
- Hız verisi
- Pitch açısı

Parametreler nasıl elde edilecek?

Hız verisi için IMU sensörünün dmp bloğundan çekeceğimiz yukarı yönlü ivme değeri, durum makinesinin haline göre low pass filtresi atılarak çekilecek ve BMP280 sensöründen gelen basınç verisi yüksekliğe çevrilip kalman içinde filtrelenerek okunacak.Burada önemli bir nokta şudur ki, yaptığımız algoritmada halihazırda DMP bloğundan filtreli gelen ivme verisinin kalman ile filtrelenmesini istemediğimiz için ölçüm adım güncellemesine bir kontrol adımı olarak direkt görev almaktadır. Ayrıca roketin hızı ve ivmesi gözetilerek IMU sensör hassasiyeti yükseltilmiştir.

Bizim için ikincil bir göreve sahip pitch açısı eğer istenen aralığın içine girerse roket apogee'ye ulaşmış gibi davranılacak.Bu verinin elde edilme yöntemi ise, yine IMU sensörünün DMP bloğu aracılığı ile okunan "quarternion" değerlerin euler açısına dönüştürülmesidir.

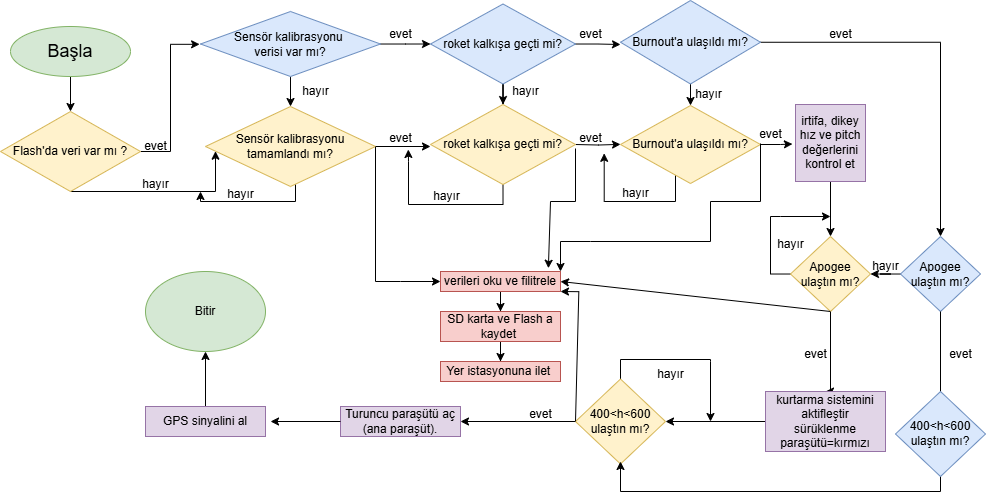
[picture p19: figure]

5 Şubat 2025 Çarşamba | 33

# Aviyonik – 1.Sistem Detay/3

### 2025 TEKNOFEST ROKET YARIŞMASI ÖN TASARIM RAPORU

# Aviyonik – 2.Sistem Detay/1

5 Şubat 2025 Çarşamba | 34 2025 TEKNOFEST ROKET YARIŞMASI ÖN TASARIM RAPORU
Adı | Kodu | Avantaj | Dezavantaj | Açıklama
Ticari Uçuş Bilgisayarı | RRC3 Sport Altimeter | Hassas ölçüm ve düşük maliyet. | Düşük frekanslı örnekleme Sadece sesli led haberleşme. IMU içermez. | Roketin uçuş fonksiyonlarının yönetimi için kullanılan bir sistemdir.
Ticari Uçuş Bilgisayarı | SkyLogic | LoRa ile uzaktan haberleşme, şifreli haberleşme ve uzun mesafe. | Daha karmaşık yapı ve kurulum. | Roketin uçuş fonksiyonlarının yönetimi için kullanılan bir sistemdir.
Ticari Uçuş Bilgisayarı | TeleMega | 9 eksenli IMU sistemine sahiptir. Mach Lockout özelliğine sahiptir | Boyut ve ağırlık olarak büyüktür. | Roketin uçuş fonksiyonlarının yönetimi için kullanılan bir sistemdir.
Ticari Uçuş Bilgisayarı | Adrel Deploymax Altimeter | Düşük güç tüketimi, yüksek ölçüm hassasiyetine ve küçük boyuta sahiptir | Tek pyro çıkışı vardır ve dual deployment desteği yok. | Roketin uçuş fonksiyonlarının yönetimi için kullanılan bir sistemdir.
Ticari Uçuş Bilgisayarı | Entacore Aım Altımeter | Yüksek akımlı pyro çıkışlara sahiptir. | Telemetri veya GPS yoktur. | Roketin uçuş fonksiyonlarının yönetimi için kullanılan bir sistemdir.

# Aviyonik – 2.Sistem Detay/1

5 Şubat 2025 Çarşamba | 35 2025 TEKNOFEST ROKET YARIŞMASI ÖN TASARIM RAPORU
Adı | Kodu | Avantaj | Dezavantaj | Açıklama
Ticari Uçuş Bilgisayarı | Lightning Bug Altimeter | 16G ivmeölçer ve Mach Lockout desteği vardır. Dayanıklı pyro sahiptir | Telemetri ve GPS desteği yok. Telemetri verileri manuel olarak alınır. | Roketin uçuş fonksiyonlarının yönetimi için kullanılan bir sistemdir.
Ticari Uçuş Bilgisayarı | EasyMini Altımeter | Yüksek veri kaydı çözünürlüğüne sahiptir. | Telemetri ve GPS yoktur. Sadece barometrik sensör kullanır. | Roketin uçuş fonksiyonlarının yönetimi için kullanılan bir sistemdir.
Ticari Uçuş Bilgisayarı | Telemetrum | Küçük boyuttadır. | Jiroskop ve manyetometre desteği yok | Roketin uçuş fonksiyonlarının yönetimi için kullanılan bir sistemdir.
Ticari Uçuş Bilgisayarı | Stratologger CF | Düşük güç tüketimi, geniş irtifa desteği ve kolay programlanabilir. | Telemetri ve GPS desteği yok | Roketin uçuş fonksiyonlarının yönetimi için kullanılan bir sistemdir.

# Aviyonik – 2.Sistem Detay/2

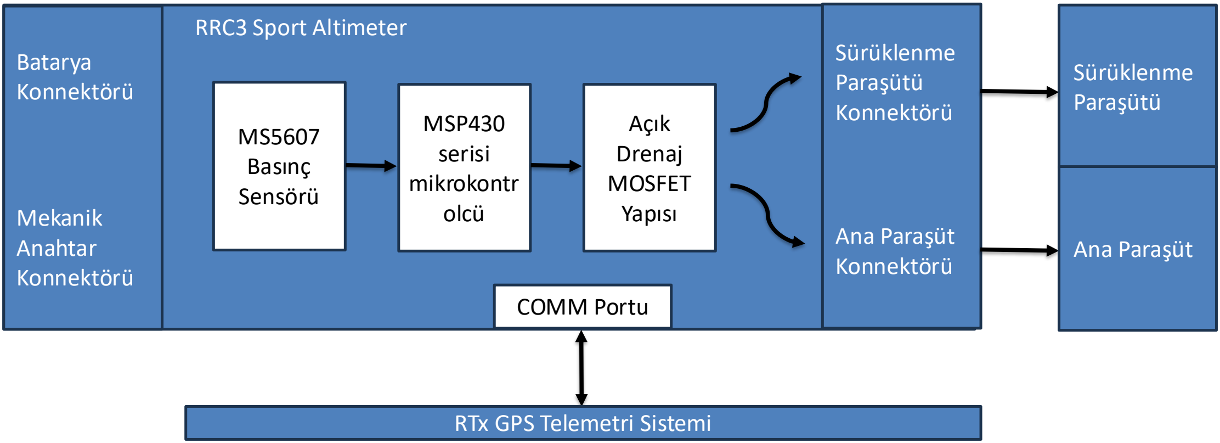
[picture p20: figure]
Sürüklenme Paraşütü Konnektörü; Ana Paraşüt Konnektörü; MS5607 Basınç Sensörü; MSP430 serisi mikrokontr olcü; Açık Drenaj MOSFET Yapısı; RRC3 Sport Altimeter; Sürüklenme Paraşütü; Ana Paraşüt; RTx GPS Telemetri Sistemi; COMM Portu; Batarya Konnektörü; Mekanik Anahtar Konnektörü

5 Şubat 2025 Çarşamba | 36 2025 TEKNOFEST ROKET YARIŞMASI ÖN TASARIM RAPORU

2S 3.7V Li-ion Pil

Mekanik Anahtar

7.4V

# Aviyonik – 2.Sistem Detay/2

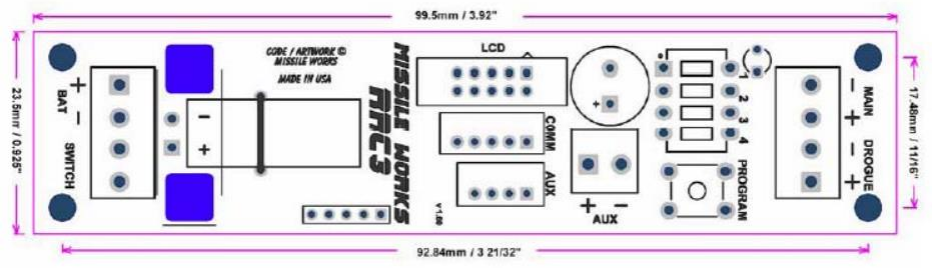
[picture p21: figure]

5 Şubat 2025 Çarşamba | 37 2025 TEKNOFEST ROKET YARIŞMASI ÖN TASARIM RAPORU

RRC3 SPORT Altimeter ticari bir ürün olup açık kaynak olmadığından tasarım yerine bu görsel paylaşılmıştır.

[ 18]

5 Şubat 2025 Çarşamba | 38

# Aviyonik – 2.Sistem Detay/3

### 2025 TEKNOFEST ROKET YARIŞMASI ÖN TASARIM RAPORU

Kurtarma sistemini tetikleyecek parametre:

Ticari UKB olarak kullanılan RRC3 Sport Altimeter'ın kurtarma sistemini tetikleyecek tek parametresi bünyesinde bulunan 24 bit analog dijital dönüştürücüye sahip yüksek hassasiyetli MS5607 basınç sensöründen elde edilen basınç verisinin hız verisine dönüştürülmesidir. MSP430 serisi mikroişlemcinin okuduğu hız değeri 0 olduğunda ticari UKB tepe noktasına ulaştığını algılamakta ve sürüklenme paraşütünü açma işlemini gerçekleştirmektedir. [19]

Kullanılan veri filtreleme yöntemleri ve hangi verilerin filtreleneceği:

RRC3 Sport Altimeter, eşdeğer bir yer değiştirme hızı belirlemek için topladığı basınç verilerine birden fazla filtreleme aşaması uygulamaktadır. Basınç verisi aşırı örneklemesi ilk olarak basınç sensörü tarafından tek bir basınç okuması elde etmek için 2048 örnek ortalaması kullanılarak gerçekleştirilir. Aşırı örneklenmiş basınç verileri sonrasında 50 Hz frekansla toplanır; ardından 20 Hz frekanslı örnek veri türetmek için tekrar ortalaması alınır. 20 Hz frekansındaki basınç verisi sonrasında 20 Hz frekanslı hız verisi elde etmek için özyinelemeli 21 elemanlı FIR filtre çekirdeğinden geçirilir. Anlatılan çok aşamalı filtreleme uygulaması RRC3 Sport Altimeter'ın yüksek hassasiyet ve tutarlılıkta hız verileri elde etmesini sağlamaktadır. [20]

Ticari UKB'de yapılacak ayarlar:

RRC3 Sport Altimeter'ı şartnameye uygun olarak konfigüre etmek için üzerinde bulunan DIP switchlere ve butona veyahut USB dongle aracılığıyla mDACS arayüzüne erişilerek gerekli ayarlar yapılacaktır. Açılma modu olarak "Dual Deploy Primary" mod seçilecektir. Bu mod sürüklenme paraşütünün tepe noktasında, ana paraşütün ise istenilen irtifada açılmasını sağlamaktadır. Ana paraşütün açılması şartnamede belirtilen değere uygun olarak seçilecektir. [21]

# Aviyonik – 2.Sistem Detay/3

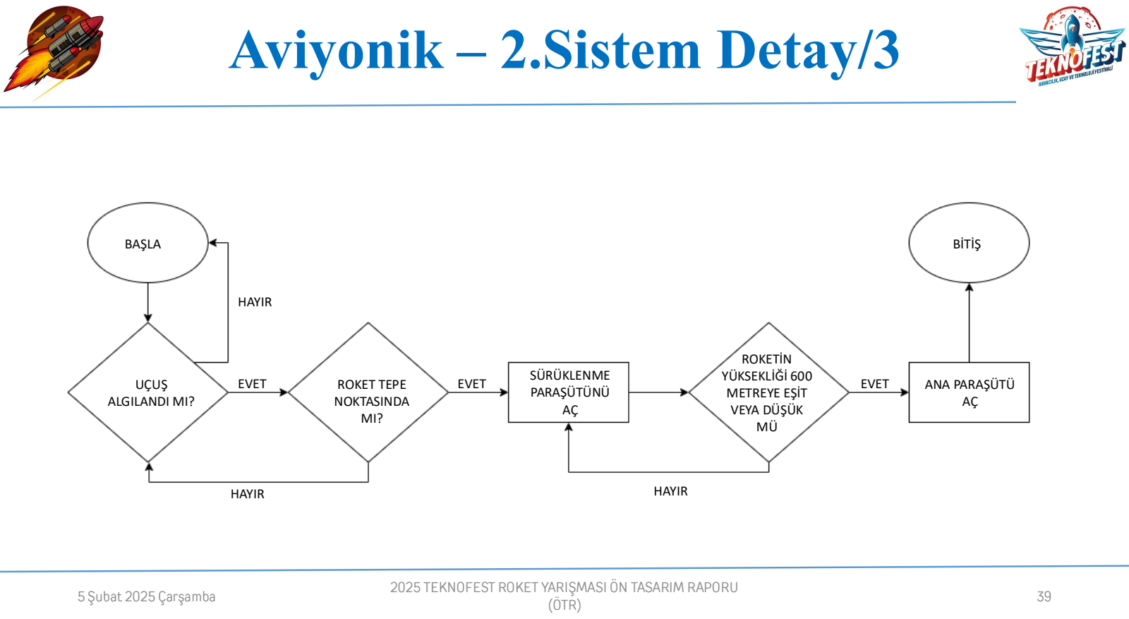
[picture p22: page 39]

5 Şubat 2025 Çarşamba | 39

### 2025 TEKNOFEST ROKET YARIŞMASI ÖN TASARIM RAPORU

BAŞLA | BİTİŞ

HAYIR

HAYIR | HAYIR
UÇUŞ | EVET | EVET | EVET
ALGILANDI MI?

ROKET TEPE
NOKTASINDA
MI?

ROKETİN
YÜKSEKLİĞİ 600
METREYE EŞİT
VEYA DÜŞÜK
MÜ

SÜRÜKLENME
PARAŞÜTÜNÜ
AÇ

ANA PARAŞÜTÜ
AÇ

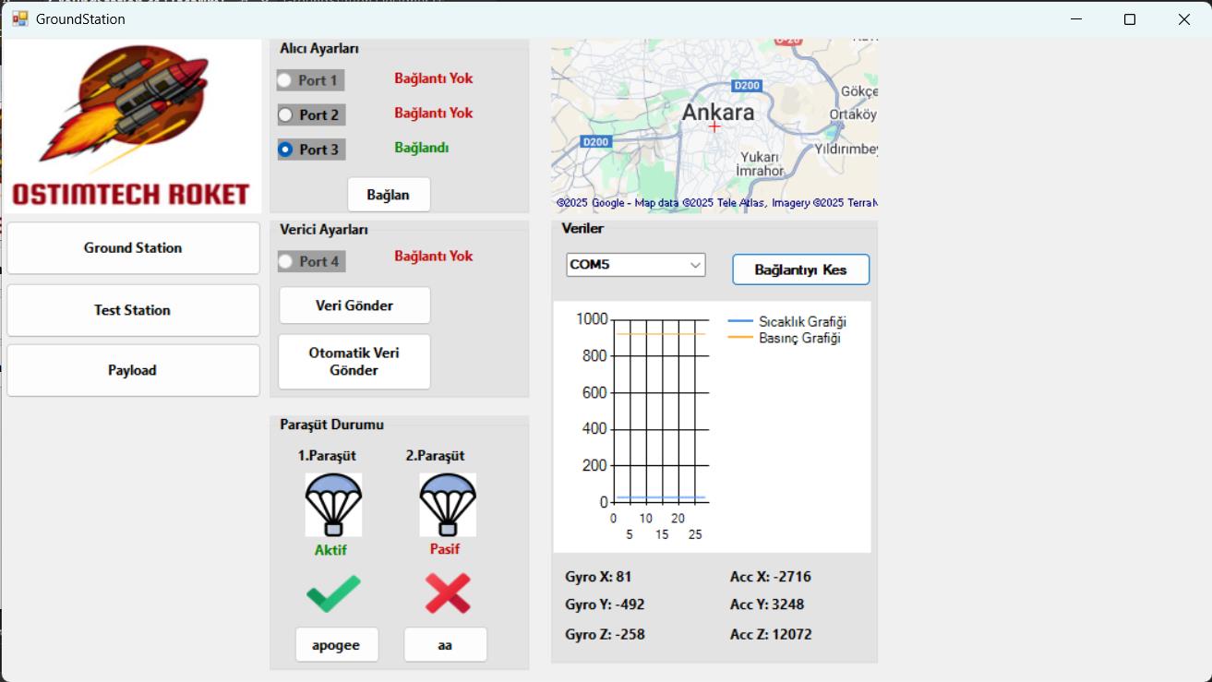
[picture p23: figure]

5 Şubat 2025 Çarşamba | 40

# Aviyonik – İletişim

### 2025 TEKNOFEST ROKET YARIŞMASI ÖN TASARIM RAPORU

Haberleşme Modülü:
- Roket ile yer istasyonu arasında iletişim için LoRa E22 900T22D haberleşme modülü kullanılacaktır.
- Modül, görev yükü, özgün sistem ve takım yer istasyonunda kullanılacaktır.
Modülün Seçilme Nedenleri:
- Aynı maliyetteki alternatif haberleşme modüllerine göre daha fazla kazanç sağlaması.
- Yüksek alma hassasiyetine sahip olması.
- Yüksek aktarma gücü.
- İletişimin şifrelenebilmesi.
Anten Seçimleri:
- Yer istasyonu için: 12 dBi kazançlı Yagi anten kullanılacaktır.
- Roket içinde: 5 dBi kazançlı SMA anten kullanılacaktır.
Görev Yükü Verileri:
- Görev yükünün gerçekleştireceği görevle alakalı olan basınç, sıcaklık ve nem bilgileri 5 Hz frekansla takım yer istasyonuna iletilecektir.
Özgün Sistem Verileri:
- 5 Hz frekansla hız, yükseklik, burun açısı ve GPS verileri takım yer istasyonuna iletilecektir.
Veri İletimi:
- Roketten gelen veriler, 868.125 MHz ISM bandında Takım ID, Sayaç, İrtifa, Roket GPS İrtifa, Roket Enlem, Roket Boylam, Görev Yükü GPS, Görev yükü Enlem, Görev Yükü Boylam, Jiroskop X, Jiroskop Y, Jiroskop Z, İvme X, İvme Y, İvme Z, Açı, Durum, CRC sıralamasıyla "EK-7 Hakem Yer İstasyonu" dökümanında belirtildiği veri boyutlarıyla aktarılacaktır.

Yer İstasyonu Arayüz

Görüntüsü

1

# Bütçe

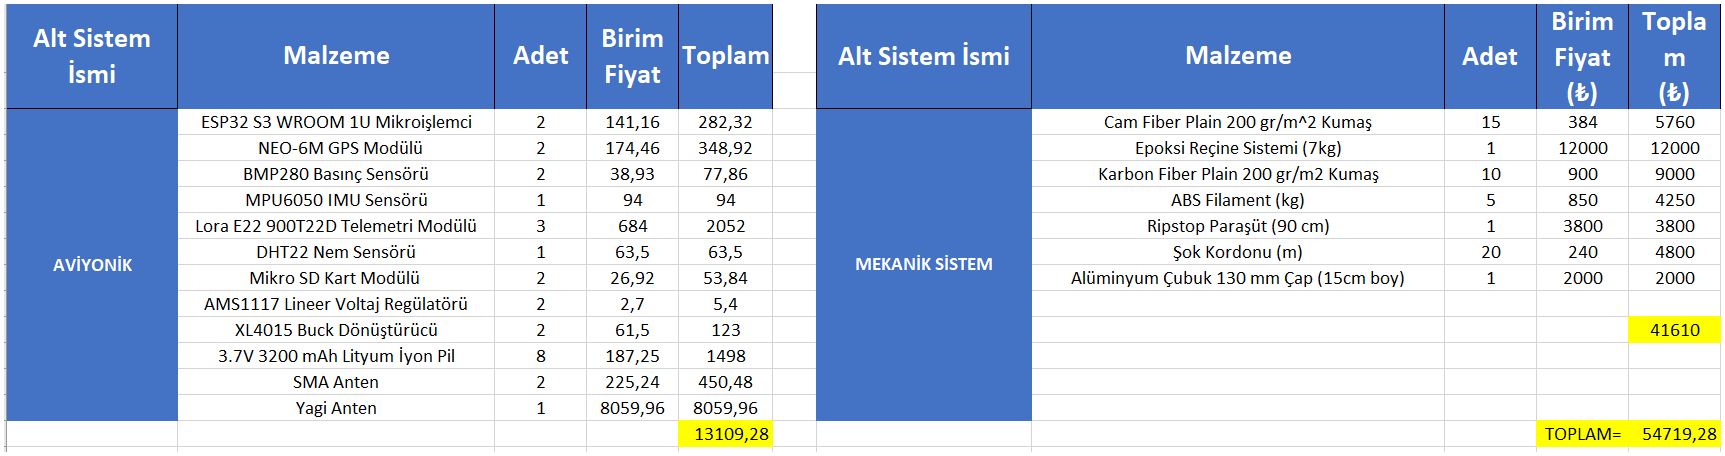
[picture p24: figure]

5 Şubat 2025 Çarşamba | 41 2025 TEKNOFEST ROKET YARIŞMASI ÖN TASARIM RAPORU

# Kontrol Listesi

5 Şubat 2025 Çarşamba | 42 2025 TEKNOFEST ROKET YARIŞMASI ÖN TASARIM RAPORU
No. | Gereksinim Madde No. | Gereksinim | Karşılanma Durumu | ÖTR Slayt No | Açıklama
1 | 3.2.2 | Yarışmaya takım halinde katılmak zorunludur. | | 2 | Yarışmaya takım halinde katılıyoruz.
2 | 3.2.3 | A Grup yarışma kategorisinde yarışacak takımlar en az altı (6), en fazla 15 (on beş) kişiden oluşmalıdır. | | 2 | Yarışmaya danışman dahil 7 kişi olarak katılıyoruz.
3 | 3.2.14 | Tablo 3.3’deki kategoriler kapsamında roket geliştirecek takımların, aşağıda verilmiş asgari irtifalardan daha düşük olmamak kaydıyla en yüksek irtifaya erişecek roketleri tasarlamaları, üretmeleri ve uçurmaları gerekmektedir aksi halde takımın uçuş performansı 1 42 başarısız sayılacaktır. | | 5 | Yapılan hesaplamalarda roketimizin 3377 metreye ulaşacağı hesaplanmıştır.
4 | 3.2.15. | A Grup yarışma kategorisi kapsamında yarışacak tüm takımlar, kategorilerindeki asgari irtifanın altında kalmamak kaydıyla hem en yüksek irtifaya ulaşmak (Tablo 3.3’deki asgari irtifalardan daha yüksek olmak kaydıyla ) hem de atış öncesinde TEKNOFEST Roket Yarışması Komitesine resmî olarak beyan ettikleri hedef irtifasına azami ±%15 (yüzde on beş) toleransla ulaşmak için yarışacaklardır. | | 5

# Kontrol Listesi

5 Şubat 2025 Çarşamba | 43 2025 TEKNOFEST ROKET YARIŞMASI ÖN TASARIM RAPORU
No. | Gereksinim Madde No. | Gereksinim | Karşılanma Durumu | ÖTR Slayt No | Açıklama
5 | 3.2.19. | A Grup yarışma kategorisinde roket geliştirecek takımlar ile B Grup yarışma kategorisinde özgün roket alt sistemleri geliştirecek takımlar için yarışma takvimi aşağıda sunulmuştur; | | | Takvime uygun hareket edilmektedir.
6 | 3.2.21. | A4 kategorisi hariç TEKNOFEST Roket Yarışması A Grup kategorisinde yer alan kategorilerin birinde bir defa birincilik ödülü alarak dereceye girmiş takımlar ve/veya bu takımların üyeleri, dereceye girdiği kategoride veya daha alt dereceli kategorilerde (A Grup kategorilerde) yarışmak için başvuruda bulunamaz. Takım veya üyesinin bu kısıta uymadığı yarışma esnasında veya sonrasında tespit edilenler yarışmadan elenmiş sayılacaktır. 1 43 | | 2 | Dereceye giren üyemiz yoktur.
7 | 3.2.22. | A4 kategorisi hariç TEKNOFEST Roket Yarışması A Grup kategorisinde yer alan kategorilerin birinde iki defa ikincilik ve/veya üçüncülük derecesi almış takımlar ve/veya bu takımların üyeleri, dereceye girdiği kategoride veya daha alt dereceli kategorilerde (A Grup kategorilerde) yarışmak için başvuruda bulunamaz. Takım veya üyesinin bu kısıta uymadığı yarışma esnasında veya sonrasında tespit edilenler yarışmadan elenmiş sayılacaktır | | 2 | Dereceye giren üyemiz yoktur.

# Kontrol Listesi

5 Şubat 2025 Çarşamba | 44 2025 TEKNOFEST ROKET YARIŞMASI ÖN TASARIM RAPORU
No. | Gereksinim Madde No. | Gereksinim | Karşılanma Durumu | ÖTR Slayt No | Açıklama
8 | 3.2.25. | Farklı eğitim-öğretim kurumlarının öğrencileri karma takımlar halinde yarışmaya katılabilirler. | | 2 | Takımımızda 2 farklı üniversiteden öğrenciler mevcuttur.
9 | 3.2.27. | Bir takım sadece bir kategoriden başvuru yapabilir ve iki veya daha fazla kategoride başvuru yaptığı tespit edilen takımlar değerlendirilmeye tabi tutulmadan yarışmadan elenir. | | | Takımımız sadece bir kategoriden başvurmuştur
10 | 3.2.28. | Bir takım sadece bir kategoriden başvuru yapabilir ve iki veya daha fazla kategoride başvuru yaptığı tespit edilen takımlar 1 44 değerlendirilmeye tabi tutulmadan yarışmadan elenir. | | | Takımımız ve üyelerimiz sadece A2 kategorisinden başvuru yapmıştır.
11 | 3.2.29. | Her takım sadece bir (1) adet roket veya sistem (A Grup Yarışma Kategorisinde yarışacaklar için roket ve B Grup Yarışma Kategorisinde yarışacaklar için sistem) ile yarışmaya katılabilir. | | | Sadece 1 adet roketle yarışmaya gidilecektir.

# Kontrol Listesi

5 Şubat 2025 Çarşamba | 45 2025 TEKNOFEST ROKET YARIŞMASI ÖN TASARIM RAPORU
No. | Gereksinim Madde No. | Gereksinim | Karşılanma Durumu | ÖTR Slayt No | Açıklama
12 | 3.2.31. | Raporların son teslim tarihleri TEKNOFEST-2025 Roket Yarışması Takviminde belirtildiği gibidir. Bu takvime uymayan takımların raporları değerlendirmeye alınmayacaktır. | | | Takvime uyulmaktadır.
13 | 3.2.33. | A1 ve A4 kategorileri hariç A Grup yarışma kategorisinde yarışan tüm takımlar Uçuş Benzetim Raporunu (UBR) hem ÖTR hem de KTR aşamalarında hazırlamaktan sorumludurlar. | | 6 | UBR hazırlanmıştır.
14 | 3.2.36. Takımlar, yarışmada görev alan takım üyeleri ve takım danışmanını | 1 45 tüm raporlarında eksiksiz listelemekten sorumludurlar. | | | Listelenmiştir.
15 | 3.2.37. | Her takımın yarışmaya bir (1) danışmanla katılması zorunludur. | | 2 | Tek danışmanımız vardır.

# Kontrol Listesi

5 Şubat 2025 Çarşamba | 46 2025 TEKNOFEST ROKET YARIŞMASI ÖN TASARIM RAPORU
No. | Gereksinim Madde No. | Gereksinim | Karşılanma Durumu | ÖTR Slayt No | Açıklama
16 | 3.2.38. Öğretmenler, akademisyenler, eğitmenler ve daha önce yurt içi | ve/veya yurt dışında düzenlenen roket yarışmalarında atış hakkı kazanmış takımların üyeleri (18 yaşından daha büyük olmak kaydıyla) danışman olabilir. | | 2 | Danışmanımız üniversitemizde öğretim görevlisi olarak görev yapmaktadır.
17 | 3.2.46. | TEKNOFEST Roket Yarışması Komitesiyle iletişim ve koordinasyon süreçlerini yürütmek üzere takım içerisinde bir kişi “KAPTAN” olarak atanmalıdır. 1 46 | | 2 | Takım kaptanımız vardır.
18 | 3.2.52. | TEKNOFEST Roket Yarışması kapsamında tüm süreçler (Başvuru Yapma, Rapor Alımı, Rapor Sonuçlarını Öğrenme, Maddi Destek Başvurusu, İtiraz Süreçleri, Üye Ekleme/Çıkarma işlemleri vb.) takım kaptanları tarafından takım danışmanıyla koordineli (takım danışmanının onayını gösterir imza ilgili tüm belgelerde yer alacak şekilde) yürütülmelidir. | | 2 | İlgili konularda danışman ve kaptan koordineli hareket etmektedir.

# Kontrol Listesi

5 Şubat 2025 Çarşamba | 47 2025 TEKNOFEST ROKET YARIŞMASI ÖN TASARIM RAPORU
No. | Gereksinim Madde No. | Gereksinim | Karşılanma Durumu | ÖTR Slayt No | Açıklama
19 | 3.2.54. | Yarışmacı, başvuru yapmadan önce yarışma hakkındaki tüm açıklamaları ve katılım koşullarını okuyup onaylayarak (başvurunun yapılması yarışmacının kuralları onayladığının göstergesi olarak kabul edilecektir) yarışmaya katılmalıdır. | | | Tüm üyelerimiz yarışma kurallarını okuyup onaylamıştır.
20 | 3.3.1.1 | Takımlar, fırlatma sonrası rokete ait tüm bileşenleri ve görev yükünü tekrar kullanılabilir şekilde kurtarmaktan sorumludurlar. | | 21,22,23 | Görev konseptimiz ve tasarımımız gerekli şartları sağlamaktadır.
21 | 3.3.1.2 | Rokete ait tüm bileşenlerin ve görev yükünün birbirinden bağımsız ve bütünsel olarak kurtarılması gerekmektedir. | | | Görev konseptimiz ve tasarımımız gerekli şartları sağlamaktadır.
22 | 3.3.1.3 | Takımlar, kurtarma işlemini paraşütle sağlamak zorundadır. | | | Kurtarma işlemlerimiz paraşütle gerçekleştirilmektedir.

# Kontrol Listesi

5 Şubat 2025 Çarşamba | 48 2025 TEKNOFEST ROKET YARIŞMASI ÖN TASARIM RAPORU
No. | Gereksinim Madde No. | Gereksinim | Karşılanma Durumu | ÖTR Slayt No | Açıklama
23 | 3.3.1.4 | Görev yüklerinin roketlerin uçuş yörüngesinin tepe noktasından (İng. apogee) hemen sonra ayrılması zorundadır. | | 5,22,24,25 | Görev yükümüz tepe noktasından hemen sonra ayrılacaktır.
24 | 3.3.1.5 | Sistem üzerindeki haberleşme bilgisayarlarıyla roketin ve görev yükünün anlık konum verilerinin kesintisiz olarak takımın yer istasyonuna paylaşılması zorunludur. 1 48 | | 24,25,40 | Görev konseptimiz ve tasarımımız gerekli şartları sağlamaktadır.
25 | 3.3.1.7 | A2, A3, A4 ve A6 kategorilerindeki roketler Şekil 3.2’deki operasyon konseptine uygun olarak uçuş görevini icra etmek zorundadır. Bu kategorilerdeki roketler, iki paraşütle (Şekil 3.1’de sarı renkli paraşüt “Birincil Paraşüt”, yeşil renkli paraşüt ise “İkincil Paraşüt”tür) kurtarılırken,görev yükünün roketten farklı bir paraşütle ( Şekil 3.2’de turuncu renkli paraşüt) kurtarılması zorunludur. | | 5,21 | Görev konseptimiz ve tasarımımız gerekli şartları sağlamaktadır.

# Kontrol Listesi

5 Şubat 2025 Çarşamba | 49 2025 TEKNOFEST ROKET YARIŞMASI ÖN TASARIM RAPORU
No. | Gereksinim Madde No. | Gereksinim | Karşılanma Durumu | ÖTR Slayt No | Açıklama
26 | 3.3.1.9 | A Grup yarışma kategorisinde yarışanların birincil paraşütlerini uçuş yörüngesinin tepe noktası (İng. apogee) ulaştıktan hemen sonra açması zorunludur. | | 5,18,21,22,23 ,24 | Görev konseptimiz ve tasarımımız gerekli şartları sağlamaktadır.
27 | 3.3.1.10 | A Grup yarışma kategorilerinde yarışanlar ikincil paraşütlerini yere 400-600 m kala açması zorunludur | | 5,18,21 | Görev konseptimiz ve tasarımımız gerekli şartları sağlamaktadır.
28 | 3.3.1.11 | A6 kategorisi hariç, A Grup kategorisinde tüm finalist takımların Aksaray Atış Alanında kullanacağı roket motorları TEKNOFEST Roket 1 49 Yarışması Komitesi tarafından tedarik edilecek katı yakıtlı ticarî ürünler olup takımların farklı motor kullanması yasaktır. | | 16 | Görev konseptimiz ve tasarımımız gerekli şartları sağlamaktadır.
29 | 3.3.1.14 | A6 kategorisi hariç, tüm takımlar roket tasarımlarını TEKNOFEST Roket Yarışması Komitesi tarafından sağlanacak motorlar için yapmak zorundadır | | 16 | Tasarımımızı A2 kategorisi için verilecek olan M1850 motoruna göre yaptık.

# Kontrol Listesi

5 Şubat 2025 Çarşamba | 50 2025 TEKNOFEST ROKET YARIŞMASI ÖN TASARIM RAPORU
No. | Gereksinim Madde No. | Gereksinim | Karşılanma Durumu | ÖTR Slayt No | Açıklama
30 | 3.3.1.21 | Takımların motorların performansını etkileyecek (itkiyi artıran veya azaltan, itkiye yön veren vb.) herhangi bir bileşen tasarımı, üretimi ve rokete entegrasyonu kesinlikle yasaktır. | | 13,14, | Tasarımımızda motorların performansını etkileyecek (itkiyi artıran veya azaltan, itkiye yön veren vb.) herhangi bir bileşen
31 | 3.3.1.22 | A5 kategorisi hariç A Grup yarışma kategorisinde seri kademeli roket tasarımları yapılmayacaktır. | | 5 | Tasarımımız tek kademelidir.
32 | 3.3.1.26 | Kurtarma işlemini yapan takımların, roketin kurtarılan bileşenleriyle birlikte altimetreyi de değerlendirmek üzere hakem heyetine elden 1 50 teslim etmesi ve herhangi bir ek müdahaleye gerek kalmadan altimetreden irtifa verisinin okunabilmesi gerekmekte olup, aksi halde takımın irtifaya bağlı başarısı TEKNOFEST Roket Yarışması Komitesi tarafından değerlendirmeye alınmayacaktır. | | | Hakem altimetresi kurtarılacaktır. Altimetreden gelen irtifa verilerinin okunması için arayüz geliştirdik.
33 | 3.3.1.29 | Kurtarılması gereken görev yükü ve roket için ayrı ayrı konum belirleyici (GPS, radyo vericisi vb.) sistem (her biri üzerinde birer adet olmak üzere) bulunacaktır. | | 22 | İlgili alt sistemler için gerekli modüllerimiz bulunmaktadır.

# Kontrol Listesi

5 Şubat 2025 Çarşamba | 51 2025 TEKNOFEST ROKET YARIŞMASI ÖN TASARIM RAPORU
No. | Gereksinim Madde No. | Gereksinim | Karşılanma Durumu | ÖTR Slayt No | Açıklama
34 | 3.3.1.30 | Şekil 3.3’deki “Open Rocket” simülasyon menüsüne uygun olarak takımların yörünge benzetimlerini gerçekleştirmesi ve ilgili raporda Open Rocket ile oluşturulmuş bu yörünge benzetim çıktısını eklemesi zorunludur, aksi halde rapor değerlendirmeye alınmayacaktır. | | 5 | OpenRocket analizlerimiz Şekil 3.3 te verilen verilerle yapılmıştır.
35 | 3.3.1.31 | Takımlar Görev Yüklerini “Unspecified Mass” ismiyle girmeyecektir. Görev Yükü “PAYLOAD” ismi ile adlandırılıp, kütlesi en az 4.000 gram (4 kg) ve tek bir parça olarak girilecektir. | | | OpenRocket tasarımımızda görev yükü PAYLOAD olarak girilmiş ve ağırlığı 4100 gr olarak girilmiştir.
36 | 3.3.1.32 | Şekil 3.3 ile verilen “Fırlatma Simülasyonu-Launch Simulation” 1 51 ekranında yer alan değerler simülasyona girilmelidir. Bu değerler ile benzetim yapmamış olan takımların raporları değerlendirmeye alınmayacaktır. | | | OpenRocket simülasyonumuz Şekil 3.3'deki veriler girilerek yapılmıştır.
37 | 3.3.1.33 | Roketler, yerden 85°’lik yükseliş açısıyla, TEKNOFEST Roket Yarışması Komitesi tarafından hâkim rüzgâr yönü esas alınarak belirlenmiş atış istikamet açısında fırlatılacaktır. | | | OpenRocket simülasyonu 85 derecelik yükseliş açısıyla yapılmıştır.

# Kontrol Listesi

5 Şubat 2025 Çarşamba | 52 2025 TEKNOFEST ROKET YARIŞMASI ÖN TASARIM RAPORU
No. | Gereksinim Madde No. | Gereksinim | Karşılanma Durumu | ÖTR Slayt No | Açıklama
38 | 3.3.1.36 | Haberleşme kabloları burgulu (İng. Twisted) yapıda olmalı (her bir cm’lik kabloda en az 10 burgu olmalı) ve burgulama işlemi High (Yüksek), Low (Düşük) ve Ground (Toprak) hatları arasında ikili veya üçlü şekilde yapılmalıdır. | | | İlgili gereksinim montaj aşamasında karşılanacaktır.
39 | 3.3.1.37 | Pil kablolarının kalınlıkları sistemin toplam sürekli ve anlık akımına göre belirlenmeli ve AWG16-28 arası tipte kablolar kullanılmalıdır | | | İlgili gereksinim montaj aşamasında karşılanacaktır.
40 | 3.3.1.38 | Bağlantılar (İng.Connector) vidalı montaja uygun olmalı ve uçuş 1 52 titreşimi göz önünde bulundurularak seçilen diğer bağlantıların montaj sonunda sabitlenmiş olmasına dikkat edilmelidir. | | | Tasarımımız ve prototip üretimimiz bu şartlar göz önüne alınarak yapılmıştır.
41 | | Kablolamalar yapıldıktan sonra her bir hattın süreklilik (devre devamlılık direnç testleri azami 1 ohm olacak şekilde) kontrollleri yapılarak doğrulanmalıdır. 3.3.1.39 | | | İlgili gereksinim montaj aşamasında karşılanacaktır.

# Kontrol Listesi

5 Şubat 2025 Çarşamba | 53 2025 TEKNOFEST ROKET YARIŞMASI ÖN TASARIM RAPORU
No. | Gereksinim Madde No. | Gereksinim | Karşılanma Durumu | ÖTR Slayt No | Açıklama
42 | 3.3.1.40 | PIN ihtiva eden bağlantılarda PIN itme ve çekme testleri icra edilmelidir (elle kuvvet uygulayarak). | | | KTR aşamasında gerçekleştirilecektir.
43 | 3.3.1.41 | PIN ihtiva eden bağlantılarda PIN’lerin arkasına epoksi, silikon vb. sabitleyici kimyasallar kullanılmalıdır. | | | İlgili gereksinim montaj aşamasında karşılanacaktır.
44 | 3.3.1.42 | Kablo demetlerinde ilave yapma ihtiyacı ortaya çıkarsa, bu 1 53 ilavelerin kablajın büküm yerlerine denk gelmemeli ve kalınlık yaratmayacak şekilde kademeli yapılmalıdır. | | | İlgili gereksinim montaj aşamasında karşılanacaktır.
45 | 3.3.2.1 | Kurtarma sistemi olarak paraşüt kullanılması zorunludur. | | 5,21,22,23 | Kurtarma paraşütle sağlanmaktadır.

# Kontrol Listesi

5 Şubat 2025 Çarşamba | 54 2025 TEKNOFEST ROKET YARIŞMASI ÖN TASARIM RAPORU
No. | Gereksinim Madde No. | Gereksinim | Karşılanma Durumu | ÖTR Slayt No | Açıklama
46 | 3.3.2.4 | A1 kategorisi hariç A Grup yarışma kategorisinde kullanılan birincil paraşütle roketin takla atması önlenmelidir. | | | Tasarımımız ve algoritmamız yapılırken bu durum gözetilmiştir ve simülasyonla test ediliştir.
47 | 3.3.2.5 | A1 kategorisi hariç A Grup yarışma kategorisinde birincil paraşütle roketin düşüş hızı azaltılmalı ancak paraşütle iniş hızı 20 m/s’den daha yavaş olmamalıdır. | | 23 | Sürüklenme paraşütüyle düşüş hızımız 23,16 m/s olarak hesaplanmıştır.
48 | 3.3.2.6 | 1 54 A1 kategorisi hariç A Grup yarışma kategorisinde ikincil paraşütle kurtarılması gereken roket ve bileşenlerinin hasar görmemesi için iniş hızının 5-9 m/s arasında olması gerekmektedir. | | 23 | Ana paraşüt için 6,65 m/s olarak hesaplanmıştır.
49 | 3.3.2.7 | A Grup kategorisinde paraşütle kurtarılması gereken görev yükünün iniş hızının 9-20 m/s olması gerekmektedir. | | 23 | Görev Yükü için 10,5 m/s olarak hesaplanmıştır.

# Kontrol Listesi

5 Şubat 2025 Çarşamba | 55 2025 TEKNOFEST ROKET YARIŞMASI ÖN TASARIM RAPORU
No. | Gereksinim Madde No. | Gereksinim | Karşılanma Durumu | ÖTR Slayt No | Açıklama
50 | 3.3.2.8 | A Grup yarışma kategorisinde görev yükleri, roketin parçalarına herhangi bir bağlantısı olmadan (hiçbir noktaya şok kordonu vb. herhangi bir ekipman ile bağlanmadan) ve kendi paraşütüyle tek başına kurtarılmalıdır. | | 5,24,25 | Görev yükümüz roketten tamamen bağımsız ayrılacaktır.
51 | 3.3.2.9 | Paraşütle kurtarma sisteminde ilgili bileşenlerin roketten ayrılmasında kimyasal tepkiyle ortaya çıkan sıcak gaz üreteçleri (barut vb.), pnömatik, mekanik, soğuk gazlı veya takım tarafından özgün geliştirilmiş sistem (çevreye zararlı olmayan ve riskleri yönetilebilen) kullanılabilir. | | 18,19,20 | Tasarımımızda sıcak gaz üreteci kullanılmaktadır.
52 | 3.3.2.10 | Paraşüt ayırma işleminde yüksek riskleri sebebiyle ticarî olmayan 1 55 basınçlı kapların (basınçlı tank, tüp vb.) kullanılmasına kesinlikle müsaade edilmeyecektir. | | 18,19,20 | Teknofest komitesi tarafınca verilien SGÜ kullanılacaktır.
53 | | Takımların sıcak gaz üreteci olarak kendi piroteknik malzemelerini kullanmalarına izin verilmeyecektir. 3.3.2.11 | | 18,19,20 | Teknofest komitesi tarafınca verilien SGÜ kullanılacaktır.

# Kontrol Listesi

5 Şubat 2025 Çarşamba | 56 2025 TEKNOFEST ROKET YARIŞMASI ÖN TASARIM RAPORU
No. | Gereksinim Madde No. | Gereksinim | Karşılanma Durumu | ÖTR Slayt No | Açıklama
54 | 3.3.2.13 | Rokette SGÜ kullanılacaksa, TEKNOFEST Roket Yarışması Komitesi tarafından sağlanan SGÜ’nün kullanıldığı takım tarafından hakem heyetine ispat edilmelidir, aksi halde takım elenecektir. | | 18,19,20 | Teknofest komitesi tarafınca verilen SGÜ kullanılacaktır.
55 | 3.3.2.15 | Yarışmada kullanılabilecek ticarî basınçlı kapların doldurulması işlemi montaj/entegrasyon alanında ve hakem heyetinin gözetiminde icra edilmelidir, aksi halde takım elenecektir. | | | Teknofest komitesi tarafınca verilen SGÜ kullanılacaktır.
56 | 3.3.2.16 | Her paraşüt birbirinden farklı renkte ve çıplak gözle uzaktan rahat seçilebilir olacaktır Paraşütlerin beyaz ve/veya mavi renklerde 1 56 veya bu renklerin farklı tonlarında olması halinde takıma 25 puan ceza uygulanacaktır. | | 21 | Paraşütlerimiz yeşil, kırmızı ve turuncu olacaktır.
57 | 3.3.2.17 | Takımlar, kurtarılması gereken görev yükü ve roket bileşenleri için konum bilgisini hakem yer istasyonuna indirilmiş verilerle hakem heyetine resmî olarak kanıtlamak zorundadır, aksi halde takıma 50 puan ceza uygulanacaktır. | | | Gerekli bilgiler arayüzde verilmiş ve iletişim kısmında sağlanıştır.

# Kontrol Listesi

5 Şubat 2025 Çarşamba | 57 2025 TEKNOFEST ROKET YARIŞMASI ÖN TASARIM RAPORU
1 | 57
No. | Gereksinim Madde No. | Gereksinim | Karşılanma Durumu | ÖTR Slayt No | Açıklama
58 | 3.3.3.1 | Tüm kategoriler için görev yükünün kütlesi asgari dört (4) kg olmalıdır. | | 23 | Görev yükümüz 4100 gr olarak tasarlanmıştır.
59 | 3.3.3.2 | Görev yükü için kütle ölçümü hakem heyeti tarafından Aksaray Atış Alanında Montaj/Entegrasyon bölgesinde yapılacak olup, ölçümün rahat bir şekilde yapılabilmesi için görev yükünün roketten kolay bir şekilde ayrılacak şekilde tasarlanması ve üretilmesi zorunludur. | | 21,24 | Görev Tasarımı kolay ayrılmayı sağlayacak şekilde yapılmıştır.
60 | 3.3.3.6 | Bilimsel görev yüklerinin roketten uçuşun tepe noktasında (İng. apogee) ayrılması (bilimsel görev yükünün yapacağı görev, uçuşun başlangıcıyla sonu arasında herhangi bir aralıkta icra edilebilir) ve bilimsel görev(ler)ine ilişkin verileri 5 Hz frekansla takımın yer istasyonuna veri indirmesi gerekmekte olup, bu frekansla veri indirimi sağlanamazsa görev tam başarılı olsa da kısmî görev başarımı yapılmış sayılacaktır. | | 24,25,40 | Veriler 5 Hz frekansla yer istasyonuna aktarılacaktır.

# Kontrol Listesi

5 Şubat 2025 Çarşamba | 58 2025 TEKNOFEST ROKET YARIŞMASI ÖN TASARIM RAPORU
No. | Gereksinim Madde No. | Gereksinim | Karşılanma Durumu | ÖTR Slayt No | Açıklama
61 | 3.3.3.7 | Bilimsel bir görevi yerine getirecek görev yükleri canlı organizma, aşındırıcı kimyasal malzeme ve radyoaktif materyal barındıramaz, çevreye/canlılara zararlı ve işletim riskleri kontrol edilemez olamazlar | | 24 | Görev yükümüzde çevreye veya sağlığa zararlı bir materyal bulunmamaktadır.
62 | 3.3.4.2 | Roketin tüm parçalarının azami dış çapları aynı değerde olmalıdır, aksi halde takımın tasarımı değerlendirme alınmayacaktır. | | 13,14 | Tüm dış çaplarımız aynı ölçüdedir.
63 | 3.3.4.3 | 1 58 Roket kademeleri arasında çap değişimine izin verilmeyecektir, aksi halde takımın tasarımı değerlendirme alınmayacaktır. | | 13,14 | Roket kademelerimiz arasında çap değişimi yoktur.
64 | 3.3.4.4 | Gövde ile gövde üzerindeki kapaklar arasında 0.1 mm’den daha büyük boşluk bırakılmayacaktır, aksi halde sızdırmazlık tedbiri alıncaya kadar hakemler tarafından takıma uygunluk verilmeyecektir. | | 13,14 | Gövde unsurlarımız arasında 0.1 mm'den daha büyük boşluğumuz yoktur.

# Kontrol Listesi

5 Şubat 2025 Çarşamba | 59 2025 TEKNOFEST ROKET YARIŞMASI ÖN TASARIM RAPORU
No. | Gereksinim Madde No. | Gereksinim | Karşılanma Durumu | ÖTR Slayt No | Açıklama
65 | 3.3.4.5 | Aktif uçuş kontrolü yapmayı sağlayacak hareketli uçuş kontrol yüzeyleri (kuyruk bölgesindeki sabit kanatçıkların hareketli versiyonu) veya roket sürüklemesini azaltacak “Boat Tail” uygulaması yasaktır, aksi halde takımın tasarımı değerlendirme alınmayacaktır | | 13,14,16 | Boat Tail veya aktif kontrol sağlayacak hareketli uçuş kontrol yüzeyimiz yoktur.
66 | 3.3.4.6 | A Grup yarışma kategorisinde roketlerin 0,3 Mach’taki stabilite değeri 1,5-2,5 arasında olmalıdır. | | 3,4 | OpenRocket analizleri 0.3 Mach için yapılmış ve stabilite değerleri sağlamaktadır.
67 | 3.3.4.7 | OpenRocket ana tasarım sayfasında 0,3 Mach için stabilite değeri 1 59 hesaplanmakta olup takımlar roketleri için bu değeri TEKNOFEST Roket Yarışması Komitesine sunmak zorundadır, aksi halde takımın tasarımı değerlendirme alınmayacaktır. | | 4 | OpenRocket analizleri 0.3 Mach için yapılmış ve stabilite değerleri sağlamaktadır.
68 | 3.3.4.9 | Takımlar, Tablo 3.10’daki kriterleri sağladığını ilgili raporlarda (ÖTR ve KTR) ve Aksaray Atış Alanındaki Montaj/Entegrasyon faaliyetlerinde TEKNOFEST Roket Yarışması Komitesine ispatlamak zorundadır aksi halde takımın raporu değerlendirmeye alınmayacaktır. | | 3 | Rampa çıkış hızımız 32,7 m/s' dir.

# Kontrol Listesi

5 Şubat 2025 Çarşamba | 60 2025 TEKNOFEST ROKET YARIŞMASI ÖN TASARIM RAPORU
No. | Gereksinim Madde No. | Gereksinim | Karşılanma Durumu | ÖTR Slayt No | Açıklama
69 | 3.3.5.1 | Roketlerin iç ve dış basınçlarının dengeli olması için roketlerin üzerinde 3,0-4,5 mm arasında çapa sahip asgari üç (3) delik bulunmak zorundadır, aksi halde Aksaray Atış Alanındaki Montaj/Entegrasyon faaliyetlerinde TEKNOFEST Roket Yarışması Komitesi tarafından rokete uçuşa elverişlilik onayı verilmeyecektir. | | 13,14 | Roketimizde belirtilen yerlerde delikler mevcuttur.
70 | 3.3.5.2 | Deliklerden birincisi roketin ön bölgesinde (roket burnu ile gövde ön bölgesi arasında), ikincisi orta bölgede (aviyonik sistemlerin bulunduğu bölge) ve üçüncüsü ise gövde arka bölgesiyle motor arasındaki bölgede olmak zorundadır, aksi halde Aksaray Atış Alanındaki Montaj/Entegrasyon faaliyetlerinde TEKNOFEST Roket 1 60 Yarışması Komitesi tarafından rokete uçuşa elverişlilik onayı verilmeyecektir. | | 13,14 | Roketimizde belirtilen yerlerde delikler mevcuttur.
71 | 3.3.5.3 | Roketler hem uçuş boyunca maruz kalacağı yapısal yüklere hem de taşıma/rampaya yerleştirme esnasında maruz kalacağı yüklere dayanıklı olmalıdır, aksi halde Aksaray Atış Alanındaki Montaj/Entegrasyon faaliyetlerinde TEKNOFEST Roket Yarışması Komitesi tarafından rokete uçuşa elverişlilik onayı verilmeyecektir. | | 13,14 | Yapılan analizler sonucu roketin yapısal yüklere dayanacağı görülmüştür.

# Kontrol Listesi

5 Şubat 2025 Çarşamba | 61 2025 TEKNOFEST ROKET YARIŞMASI ÖN TASARIM RAPORU
No. | Gereksinim Madde No. | Gereksinim | Karşılanma Durumu | ÖTR Slayt No | Açıklama
72 | 3.3.5.4 | Roketlerin aerodinamik kuvvetlere maruz kalan yüzeylerinde (gövde, kanatçık, burun) malzeme olarak PVC, sıkıştırılmış kağıt/kraft veya PLA kullanılması yasaktır, aksi halde takım elenir. | | | Belirtilen malzemeler roketin aerodinamik ve mekanik yüklere maruz kalan yüzeylerinde kullanılmamıştır.
73 | 3.3.5.5 | Roketlerin aerodinamik kuvvetlere maruz kalan yüzeylerinde (gövde, kanatçık, burun) veya roket içerisinde dayanımlı olmayı (mukavim) gerektiren yerlerinde ilgili raporlarda (ÖTR ve KTR) bununla ilgili gerekli analizlerin sunulmadığı veya sağlamlık testlerinin (çekme, basma ve burulma testleri) olumlu sonuçlarının ilgili raporda (AHR) gösterilmediği durumlarda takım elenecektir. | | | KTR aşamasında eklenecektir.
74 | 3.3.5.6 | Roketlerin tüm alt bileşenlerinin yapısal (kanatçık, motor bloğu, 1 61 merkezleme halkası vb.) bağlantı bölgeleri üzerine gelebilecek yüklere karşı dayanıklı (rijit) olduğu analiz ve testlerle (çekme, basma ve burulma testleri) ilgili raporlarda (ÖTR, KTR ve AHR) ispatlanmak zorundadır. | | | KTR aşamasında eklenecektir.
75 | 3.3.5.7 | Kullanılacak mapaların (İng. eye bolt) tek parça ve döküm çelikten imal edilmiş olması zorunludur, aksi halde takıma 25 puan ceza uygulanacaktır. | | 9,19,24 | İlgili malzemeler şartnamede belirtilen şekilde seçilmiştir.

# Kontrol Listesi

5 Şubat 2025 Çarşamba | 62 2025 TEKNOFEST ROKET YARIŞMASI ÖN TASARIM RAPORU
No. | Gereksinim Madde No. | Gereksinim | Karşılanma Durumu | ÖTR Slayt No | Açıklama
76 | 3.3.5.8 | Büküm mapalar ile mapa yerine kullanılabilecek veya mapa ile benzer kuvvetlere maruz kalabilecek parçaların kullanımına izin verilmeyecektir, aksi halde Aksaray Atış Alanındaki Montaj/Entegrasyon faaliyetlerinde TEKNOFEST Roket Yarışması Komitesi tarafından rokete uçuşa elverişlilik onayı verilmeyecektir. | | | İlgili malzemeler şartnamede belirtilen şekilde seçilmiştir.
77 | 3.3.5.9 | Burun omuzluğunun diğer gövdeye girecek kısmının gövde dış çapının en az bir buçuk (1,5) katı olması zorunludur, aksi halde takımın raporu değerlendirmeye alınmayacaktır. | | 4,9 | Burun omuzluğu çapın 1.5 katı uzunlukta olacak şekilde tasarlanmıştır.
78 | 3.3.5.10 | Entegrasyon gövdelerinin entegre edilecekleri gövdelerin her ikisine 1 62 de gövde dış çapının en az (0,75) katı kadar girmesi gerekmektedir, aksi halde takımın raporu değerlendirmeye alınmayacaktır. | | 4,13 | Entegrasyon gövdesi belirtilen şartı sağlamaktadır.
79 | 3.3.5.14 | Kaydırma ayakları, gövdenin yapısal olarak güçlendirilmiş bölgelerine takılmak zorundadır, aksi halde TEKNOFEST Roket Yarışması Komitesi tarafından rokete uçuşa elverişlilik onayı verilmeyecektir. | | 4,13,14 | Kaydırma ayakları gövdenin yapısal olarak güçlendirilmiş bölgelerindedir.

# Kontrol Listesi

5 Şubat 2025 Çarşamba | 63 2025 TEKNOFEST ROKET YARIŞMASI ÖN TASARIM RAPORU
No. | Gereksinim Madde No. | Gereksinim | Karşılanma Durumu | ÖTR Slayt No | Açıklama
80 | 3.3.5.15 | Bir rokette asgari iki (2) adet kaydırma ayağı bulunmak zorundadır, aksi halde TEKNOFEST Roket Yarışması Komitesi tarafından rokete uçuşa elverişlilik onayı verilmeyecektir. | | | 2 adet kaydırma ayağı mevcuttur.
81 | 3.3.5.16 | Roketin ağırlık merkezi iki kaydırma ayağının arasında olmak zorundadır, aksi halde TEKNOFEST Roket Yarışması Komitesi tarafından rokete uçuşa elverişlilik onayı verilmeyecektir. | | | Ağırlık merkezi 2 kaydırma ayağının ortasındadır.
82 | 3.3.5.17 | Kaydırma ayaklarından birinin motor bölgesinde (motorun ağırlık merkezi ile gövde sonu arasında) olması zorunludur, aksi halde 1 63 TEKNOFEST Roket Yarışması Komitesi tarafından rokete uçuşa elverişlilik onayı verilmeyecektir. | | | Kaydırma ayakları belirtilen konumlarda olacak şekilde tasarlanmıştır.
83 | 3.3.5.18 | Kaydırma ayakları sabitlenirken fiberli somun, yaylı rondela ve tırtıklı rondela gibi ön yükleme oluşturan ve kendi kendine sökülmeyi zorlaştıran önlemlerin alınması zorunludur, aksi halde TEKNOFEST Roket Yarışması Komitesi tarafından rokete uçuşa elverişlilik onayı verilmeyecektir. | | 13,14 | Kaydırma ayakları kendi kendine sökülmeyi zorlaştıracak şekilde montajlanacaktır.

# Kontrol Listesi

5 Şubat 2025 Çarşamba | 64 2025 TEKNOFEST ROKET YARIŞMASI ÖN TASARIM RAPORU
No. | Gereksinim Madde No. | Gereksinim | Karşılanma Durumu | ÖTR Slayt No | Açıklama
84 | 3.3.5.19 | Roket kesit alanında çıkıntı yaratan parçalar (sensör, anten, kamera vb.) rokete sabitlenmiş olmak zorundadır, aksi halde TEKNOFEST Roket Yarışması Komitesi tarafından rokete uçuşa elverişlilik onayı verilmeyecektir. | | 13,14 | Roket kesit alanında çıkıntı yaratan parçamız yoktur.
85 | 3.3.5.20 | Roket kesit alanında çıkıntı yaratan parçaların, roketin yanması bittikten sonra ortaya çıkan roket yeni kütle merkezinin ilerisinde olması zorunludur, aksi halde TEKNOFEST Roket Yarışması Komitesi tarafından rokete uçuşa elverişlilik onayı verilmeyecektir. | | 13,14 | Roket kesit alanında çıkıntı yaratan parçamız yoktur.
86 | 3.3.5.21 | A5 kategorisi hariç olmak üzere Uçuş Kontrol Bilgisayarı (UKB) ve 1 64 Görev Yükü ile ilgili tüm anahtarların roket nozulundan azami 2,5 m mesafede olması zorunludur, aksi halde aksi halde takıma 50 puan ceza uygulanacaktır. | | 4,13,14 | Uçuş Kontrol Bilgisayarı (UKB) ve roket nozulundan azami 2,5 m mesafededir.
87 | 3.3.5.22 | Roketlerdeki tüm anahtarların aktifleştirilmesine rampa üzerinde ve atışa hazır konumdayken izin verilecektir. | | | Roketlerdeki tüm anahtarların aktifleştirilmesine rampa üzerinde ve atışa hazır konumdayken yapılacaktır.

Görev Yükü ile ilgili tüm anahtarların

# Kontrol Listesi

5 Şubat 2025 Çarşamba | 65 2025 TEKNOFEST ROKET YARIŞMASI ÖN TASARIM RAPORU
No. | Gereksinim Madde No. | Gereksinim | Karşılanma Durumu | ÖTR Slayt No | Açıklama
88 | 3.3.5.23 | Tüm anahtarlar aktifleştirilirken herhangi bir vida sökme/sıkma işlemi, kapak açma/kapama işlemine ihtiyaç duyulmayacak şekilde tasarım ve üretim yapılmış olmalıdır, aksi halde takıma 50 puan ceza uygulanacaktır. | | | Tüm anahtarlar aktifleştirilirken herhangi bir vida sökme/sıkma işlemi, kapak açma/kapama işlemine ihtiyaç duyulmayacak şekilde tasarım yapılmıştır.
89 | 3.3.5.24 | Roket, aynı anda burun konisi ucundan ve kanatçıklardan tutularak kaldırıldığında yapısal olarak herhangi bir deformasyona uğramaması, roketin doğrusallığını koruması (bel vermemesi) ve roket gövdesi ve burun konisi bağlantılarının açılmaması/gevşememesi zorunludur, aksi halde TEKNOFEST Roket Yarışması Komitesi tarafından rokete uçuşa elverişlilik onayı verilmeyecektir. | | 13,14 | Roket belirtilen şekilde tasarlanmıştır.
90 | 3.3.5.25 | 1 65 Roket üzerinde bulunan kapakların mekanik olarak sabitlenmesi zorunludur, aksi halde TEKNOFEST Roket Yarışması Komitesi tarafından rokete uçuşa elverişlilik onayı verilmeyecektir. | | 13,14 | Roket üzerindeki kapaklar mekanik olarak sabitlenecek şekilde tasarlanmıştır.
91 | 3.3.6.1 | Rokette bulunan kurtarma sistemlerinin, roket üzerindeki tüm UKB’ler (A1 kategorisinde UKB veya UKB’ler) tarafından yönetilmesi zorunludur. | | 30,36 | İlgili görsellerde yönetici UKB'ler belirtilmiştir.

# Kontrol Listesi

5 Şubat 2025 Çarşamba | 66 2025 TEKNOFEST ROKET YARIŞMASI ÖN TASARIM RAPORU
No. | Gereksinim Madde No. | Gereksinim | Karşılanma Durumu | ÖTR Slayt No | Açıklama
92 | 3.3.6.2 | Kategoriye bağlı olarak rokette kullanılacak UKB sayısı değişkenlik göstermekle birlikte, A Grup kategorisinde kullanılacak UKB’lerden birisinin ticarî UKB olması zorunludur, aksi halde takımın tasarımı değerlendirme alınmayacaktır. | | 36 | Özgün UKB'nin yanında olacak olan ticari RRC3 UKB'si belirtilmiştir.
93 | 3.3.6.3 | Takımların kullanacağı ticari UKB’lerin EK-5’de listelenmiş ürünlerden (TEKNOFEST Roket Yarışması Komitesi tarafından onaylanmış ürünler) seçilmesi zorunludur, aksi halde takımın tasarımı değerlendirme alınmayacaktır. | | 36 | RRC3, EK-5 içerisinde bulunan bir UKB'dir.
94 | 3.3.6.5 | 1 66 Roketlerin uçuş boyunca telemetri verilerini kesintisiz olarak takımın yer istasyonuna aktarılmasında kullanılabilecek haberleşme sistemi UKB’den bağımsız veya entegre görev yapabilir. | | 30,36 | Özgün UKB'de devre içinde entegre iken, Ticari UKB'de RRC3'ün haberleşme ve GPS modülü kullanılacaktır.
95 | 3.3.6.8 | Ticarî UKB’de konum belirleme ve haberleşme sistemi bulunmuyorsa takımların ayrıca haberleşme bilgisayarı kullanması/geliştirmesi zorunludur, aksi halde takımın tasarımı değerlendirme alınmayacaktır. | | 36 | Ticari UKB'ye uyumlu GPS ve Haberleşme modülü temin edilecektir.

# Kontrol Listesi

5 Şubat 2025 Çarşamba | 67 2025 TEKNOFEST ROKET YARIŞMASI ÖN TASARIM RAPORU
No. | Gereksinim Madde No. | Gereksinim | Karşılanma Durumu | ÖTR Slayt No | Açıklama
96 | 3.3.6.9 | A1 kategorisi hariç A Grup yarışma kategorisinde, birisi ana diğeri yedek olacak şekilde en az iki (2) UKB kullanılması zorunludur, aksi halde takımın tasarımı değerlendirme alınmayacaktır. | | 30,36 | İki adet UKB bulunmaktadır.
97 | 3.3.6.10 | A1 kategorisi hariç A Grup yarışma kategorisinde kullanılacak ana UKB’nin özgün geliştirilmiş ürün ve yedek UKB’nin ticarî ürün olması zorunludur, aksi halde takımın tasarımı değerlendirme alınmayacaktır. | | 30,36 | UKB'ler verilen şartlara uymaktadır.
98 | 3.3.6.11 | 1 67 Özgün UKB’de kullanılan uçuş algoritmasının takım üyeleri tarafından özgün tasarlanmış olması zorunludur, aksi halde takımın tasarımı değerlendirme alınmayacaktır. | | 30,36 | UKB'ler arasında bir bağlantı bulunmamaktadır.
99 | 3.3.6.14 | Özgün geliştirilmiş veya ticarî UKB’ler birbirinden tamamen bağımsız çalışmak zorundadır aksi halde TEKNOFEST Roket Yarışması Komitesi tarafından rokete uçuşa elverişlilik onayı verilmeyecektir. | | 33 | Algoritma ekip üyelerimiz tarafından tamamen özgün olarak tasarlanmıştır.

# Kontrol Listesi

5 Şubat 2025 Çarşamba | 68 2025 TEKNOFEST ROKET YARIŞMASI ÖN TASARIM RAPORU
No. | Gereksinim Madde No. | Gereksinim | Karşılanma Durumu | ÖTR Slayt No | Açıklama
100 | 3.3.6.15 | Özgün geliştirilmiş veya ticari UKB’lerin kendisine ait özel işlemcisi, sensörleri, güç kaynağı ve kablolaması olmak zorundadır, aksi halde TEKNOFEST Roket Yarışması Komitesi tarafından rokete uçuşa elverişlilik onayı verilmeyecektir. | | 30,36 | UKB'ler birbirinden tamamen farklıdır, eyleyici noktasındaki birleşime kadar hiçbir bağ bulunmamaktadır, o bağda ise eyleyici harekete geçirme kararı tamamen bağımsız alınmaktadır.
101 | 3.3.6.18 | Özgün geliştirilmiş UKB’ye asgari iki (2) farklı sensörün bağlantısı olmalı, ticari UKB’ye ise asgari bağlantı sınırı yoktur (farklı UKB’lere bağlanan sensörler aynı olabilir), aksi halde TEKNOFEST Roket Yarışması Komitesi tarafından rokete uçuşa elverişlilik onayı verilmeyecektir. | | 30 | Özgün UKB içinde 2 adet farklı sensör vardır.
102 | 3.3.6.19 | Özgün geliştirilmiş veya ticari UKB’lere bağlı sensörlerden en az 1 68 birinin basınç sensörü olması zorunludur, aksi halde TEKNOFEST Roket Yarışması Komitesi tarafından rokete uçuşa elverişlilik onayı verilmeyecektir. | | 30 | Özgün UKB'de BMP280 isimli bir basınç sensörü bulunmaktadır.
103 | 3.3.6.20 | Özgün geliştirilmiş veya ticari UKB’lere bağlı iki (2) adet basınç sensörü verisi kullanılması durumunda sensörlerin birbirinden farklı olması zorunludur, aksi halde TEKNOFEST Roket Yarışması Komitesi tarafından rokete uçuşa elverişlilik onayı verilmeyecektir. | | 30 | Yalnızca bir basınç sensörümüz vardır.

# Kontrol Listesi

5 Şubat 2025 Çarşamba | 69 2025 TEKNOFEST ROKET YARIŞMASI ÖN TASARIM RAPORU
No. | Gereksinim Madde No. | Gereksinim | Karşılanma Durumu | ÖTR Slayt No | Açıklama
104 | 3.3.6.21 | Özgün geliştirilmiş UKB’lerin gömülü uçuş kontrol algoritmasında en az iki (2) farklı sensörden gelen veriler kullanılmalıdır, aksi halde TEKNOFEST Roket Yarışması Komitesi tarafından rokete uçuşa elverişlilik onayı verilmeyecektir. | | 32 | Algoritmamızda MPU6050 ve BMP280 sensörlerinden gelen veriler füzyonlanmaktadır.
105 | 3.3.6.22 | Uçuş algoritmalarında ayrılma sekanslarını tetikleyecek asgari iki (2) bağımsız kriter kullanılması zorunludur. | | 33 | Füzyonlanan sensörlerden gelen veriler harici açı verisi de kontrol edilerek 2 farklı bağımsız veride doğruluk aranmaktadır.
106 | 3.3.6.23 | 1 69 Karar verme parametrelerinde sensörlerden okunan verilerin esas alınması zorunludur. | | 33 | Tümüyle sensör verilerinden karar alınmaktadır.
107 | 3.3.6.24 | Sensörlerden okunan veriler doğrudan kullanılmamalı ve herhangi bir hatalı okuma ya da sensör hatası durumu göz önünde bulundurulmalıdır. | | 32 | Her iki sensör de füzyonlama ve filtreleme işlemine tabi tutulmaktadır.

# Kontrol Listesi

5 Şubat 2025 Çarşamba | 70 2025 TEKNOFEST ROKET YARIŞMASI ÖN TASARIM RAPORU
No. | Gereksinim Madde No. | Gereksinim | Karşılanma Durumu | ÖTR Slayt No | Açıklama
108 | 3.3.6.25 | Sensörlerden gelebilecek hatalı veriler için alınacak önlemler (filtreleme vb.) ilgili tasarım raporlarında (ÖTR ve KTR) detaylı anlatılmalıdır. | | 32 | İlgili anlatım ÖTR'nin belirlenmiş bölümünde yapılmıştır.
109 | 3.3.6.26 | Takımdaki aviyonik sorumlusu uçuş algoritmalarını alanda revize edebilecek yetkinlikte olmak zorundadır. | | | Aviyonik sorumlumuz algoritmayı açıklayacak ve revize edecek yetkinliktedir.
110 | 3.3.6.27 | A1 kategorisi hariç A Grup yarışma kategorisinde kullanılan 1 70 UKB’lerden en az biri haberleşme bilgisayarı özellikleri taşıyabilir veya haberleşme için ayrı bir sistem kullanılabilir. | | 30,36 | İki bilgisayar da haberleşme işlemini yapmaktadır.
111 | 3.3.6.28 | Kurtarma sisteminin aktifleşmesini dijital sinyallerle sağlamayan takımlar, sistemlerinde ticarî UKB kullanabilmek için dijital ateşleme çıkışıyla eyleyici sürme kabiliyeti olan ara elektronik bileşenini beraber kullanabilirler. | | 30,36 | Kurtarma sisteminin aktifleşmesi dijital sinyalle sağlanmıştır.

# Kontrol Listesi

5 Şubat 2025 Çarşamba | 71 2025 TEKNOFEST ROKET YARIŞMASI ÖN TASARIM RAPORU
No. | Gereksinim Madde No. | Gereksinim | Karşılanma Durumu | ÖTR Slayt No | Açıklama
112 | 3.3.6.29 | Söz konusu eyleyici sürme kabiliyeti olan ara elektronik bileşen, sadece ticarî UKB’den gelen sinyalleri değerlendirmeli ve herhangi bir sensör verisi ile durum değerlendirmesi yapmamalıdır. | | | Herhangi bir değerlendirme yapılmamıştır.
113 | 3.3.6.30 | Eyleyici tek ise, (A1 kategorisi hariç) hem birincil hem de ikincil UKB tarafından kontrol edilmelidir. | | 18,19,20,30,3 6 | Eyleyici sistemi slayt kısımlarında açıklanmaktadır.
114 | 3.3.6.32 | 1 71 Eyleyici tek ise, sistem kontrolsüz bir şekilde aktif hale gelmemelidir. | | | Gerekli testlerimizde sorun görülmemiştir.
115 | 3.3.6.35 | Ayrılma sistemlerine bağlı eyleyiciler yedekli olmak zorunda değildir (yaylı bir sistemde yay, DC motorlu bir sistemde DC motor vb.). | | 30,36 | Eyleyicilerimiz ayrılma sistemine bağlı değildir.

# Kontrol Listesi

5 Şubat 2025 Çarşamba | 72 2025 TEKNOFEST ROKET YARIŞMASI ÖN TASARIM RAPORU
No. | Gereksinim Madde No. | Gereksinim | Karşılanma Durumu | ÖTR Slayt No | Açıklama
116 | 3.3.6.37 | Bütün takımların, roketlerinden ve faydalı yüklerinden anlık ve sürekli veri alabilen bir yer istasyonuna sahip olması zorunludur, aksi halde TEKNOFEST Roket Yarışması Komitesi tarafından rokete uçuşa elverişlilik onayı verilmeyecektir. | | 40 | İletişim kısmında olan arayüz yer istasyonunda bulunacaktır, yer istasyonuna bağlı bir alıcı ve bir de kontrol kartı da olmaktadır.
117 | 3.3.6.38 | Roketlerin anlık konum verilerinin yarışmacı yer istasyonu aracılığıyla Hakem Yer İstasyonuna (teknik detayları EK-7’de verilmiş) sürekli iletilmesi zorunludur, aksi halde TEKNOFEST Roket Yarışması Komitesi tarafından rokete uçuşa elverişlilik onayı verilmeyecektir. | | 40 | Tüm gerekli verilerin iletişimi gerçekleştirilecektir.
118 | 3.3.6.42 | 1 72 Roket parçalarının yer istasyonundan uzak yerlere düşeceği göz önüne alınmalı ve alıcı-verici antenlerin menzili roketlerin uçuş yörüngesi dikkate alınacak şekilde seçilmelidir. | | 40 | Antenlerimizin yeterli dbi değeri bulunmaktadır, KTR içinde bununla alakalı hesaplamalara yer verilecektir.
119 | 3.3.6.43 | RF modülünün gücü değerlendirilerek link bant genişliği bütçesinin yapılması ve ilgili tasarım raporlarında sunulması gerekmektedir. | | 40 | Link bütçesi yeterlidir, ilgili hesaplamalar KTR'de sunulacaktır.

# Kontrol Listesi

5 Şubat 2025 Çarşamba | 73 2025 TEKNOFEST ROKET YARIŞMASI ÖN TASARIM RAPORU
No. | Gereksinim Madde No. | Gereksinim | Karşılanma Durumu | ÖTR Slayt No | Açıklama
120 | 3.3.6.44 | Roket üzerindeki aviyonik sistemler ve sensörler uçuş esnasında maruz kalacakları titreşim, basınç ve şok gibi etkiler altında görevlerini rahatlıkla yerine getirmelidir. | | 33 | Algoritma tasarımında ve yaptığımız deneylerde bu unsur en çok dikkat ettiğimiz noktadır.
121 | 3.3.6.45 | Titreşim, basınç ve şok gibi etkiler için takımlar tarafından gerekli koruyucu önlemler alınmalı, tasarım doğrulama aşamasında ilgili testler gerçekleştirilmeli ve sonuçları ilgili tasarım raporlarında sunulmalıdır. | | 32 | Algoritmamızda yapılan filtreleme ve veri kaydetme gibi önlemler ile bu kısım karşılanmaktadır.
122 | 3.3.6.47 | Sisteme güç sağlayan sistemle (akü, pil, süper kapasitör vb.) bu 1 73 sistemin beslediği ilk devrelerin arasında açma/kapama anahtarı (Ing. ON/OFF switch) olarak mekanik anahtar (İng. Key Switch) kullanılmalıdır, aksi halde TEKNOFEST Roket Yarışması Komitesi tarafından rokete uçuşa elverişlilik onayı verilmeyecektir. | | 30,36 | Sistemimizde mekanik anahtar kullanılacak şekilde planlama yapılmıştır.
123 | 3.3.6.48 | Mekanik anahtar vasıtasıyla bağlantı kesildiğinde, güç besleme elemanının herhangi bir sistem elemanıyla (LED göstergeler, güç çeviriciler, regülatorler de dahil olmak üzere) bağlantısı olmamalıdır. | | 30,36 | Güç besleme, tümüyle anahtara bağlıdır.

# Kontrol Listesi

5 Şubat 2025 Çarşamba | 74 2025 TEKNOFEST ROKET YARIŞMASI ÖN TASARIM RAPORU
No. | Gereksinim Madde No. | Gereksinim | Karşılanma Durumu | ÖTR Slayt No | Açıklama
124 | 3.3.6.49 | UKB’ler ve Bilimsel Görev Yüküne (Bilimsel Görev Yükü içerisindeki elektronik devrelere ) enerji verilmesi/kesilmesi için kullanılacak mekanik anahtarın (İng. Key Switch) rampa operasyonlarında rahat erişilebilir olması, enerji verildiğinde anahtara bağlı ışığın yanması/sesli uyarı alınması ve aerodinamik etkiler dikkate alınarak gömülü olması için gerekli tasarım ve üretim yapılmalıdır, aksi halde TEKNOFEST Roket Yarışması Komitesi tarafından rokete uçuşa elverişlilik onayı verilmeyecektir. | | 13,14,30 | Buzzer gibi sistemler ile bu sağlanmaktadır.
125 | 3.3.6.54 | Kullanılacak piller roketin ihtiyacını karşılayabilecek kapasitede ve yeterince dolu olmasından takım sorumludur. 1 74 | | 30,36 | Gerekli güç bütçesi hesapları yapılmıştır, ayrıntılar KTR içinde paylaşılacaktır.
126 | 3.3.7.1 | Tasarım ve üretim aşamalarında kullanılacak malzeme, donanım ve süreçler insan sağlığına ve çevreye zararlı olmamalıdır. | | | Hiçbir zararlı malzeme dizaynımızda yer almamıştır.

# Kontrol Listesi

5 Şubat 2025 Çarşamba | 75 2025 TEKNOFEST ROKET YARIŞMASI ÖN TASARIM RAPORU
1 | 75
No. | Gereksinim Madde No. | Gereksinim | Karşılanma Durumu | ÖTR Slayt No | Açıklama
127 | 3.3.7.2 | Tasarım, üretim ve test süreçleri kapsamında gerekli güvenlik risk analizleri ve riskleri indirgemeye yönelik çalışmalar yapılmalı ve ilgili tasarım (ÖTR, KTR ve AHR) raporlarında bu çalışmaların yapıldığı ispatlanmak zorundadır. | | 76 | Hata türleri ve analizi detaylı şekilde uygulanmıştır.
128 | 3.3.7.3 | Tasarım, üretim, entegrasyon ve atış faaliyetlerinde güvenliği riske sokacak unsurlar önceden belirlenmeli, gerekli tedbirler eksiksiz planlanmalı ve icra edildiği kanıtlanmalıdır, aksi halde takım elenir | | 76 | Hata türleri ve analizi sistemi dizayn etmeden önce ve ederken uygulanmış, çıkabilecek sorunlar düşünülerek tasarım yapılmıştır.

# HTEA Hata Türleri ve Etkileri Analizi

5 Şubat 2025 Çarşamba | 76
- Hata Türleri ve Etkileri Analizi (HTEA) belgemiz ek olarak eklenmiştir.

### 2025 TEKNOFEST ROKET YARIŞMASI ÖN TASARIM RAPORU

5 Şubat 2025 Çarşamba | 2025 TEKNOFEST ROKET YARIŞMASI ÖN TASARIM RAPORU
77

# Referanslar

- [1] Chin SS. (1961). Missile Configuration Design. McGraw-Hill Book Co., Inc., New York. (2024, Aralık). Erişim Adresi: [https://tr.wikipedia.org/wiki/Burun_konisi_tasarımıhttps://tr.wikipedia.org/wiki/Burun_konisi_tasarımı]
- [2] Richard Nakka's Experimental Rocketry. Inroduction to Rocket Design. (2023, Temmuz). Erişim Adresi: [https://www.nakka-rocketry.net/RD_nosecone.html]
- [3] [4] Polimer Matris Kompozitler; Üretim Prosesleri (2025, Şubat). Erişim Adresi: [https://bilsenbesergil.blogspot.com/p/blog-page_96.html]
- [5] Sıcak Gaz Üreteci Hesaplama. Roketsan Temel Roketçilik Eğitimi (2023, Kasım). 5.4.1.1.2. Gerekli Basınsın Hesaplanması Syf.162.
- [6] Richard Nakka's Experimental Rocketry. Parachute Design and Construction. (2023, Temmuz). Erişim Adresi: [https://www.nakka-rocketry.net/paracon.html]
- [7] Tom Benson. The Drag Equation. (2025, Şubat). Erişim Adresi: [https://www.grc.nasa.gov/www/k-12/VirtualAero/BottleRocket/airplane/drageq.html]
- [8] RRC3 Classic Altimeter. (Mart, 2025). Erişim Adresi: [https://store2263081.ecwid.com/RRC3-Classic-Altimeter-p25239688]
- [9] Missile Works Corporation. Rocket Recovery Controller 3 User Manual. (Şubat, 2025) Erişim Adresi: [https://www.apogeerockets.com/downloads/PDFs/RRC3-user-manual.pdf] (https://www.apogeerockets.com/downloads/PDFs/RRC3-user-manual.pdf)
- [10]Missile Works Corporation. Rocket Recovery Controller 3 User Manual. (Şubat, 2025) Erişim Adresi: [https://www.apogeerockets.com/downloads/PDFs/RRC3-user-manual.pdf] (https://www.apogeerockets.com/downloads/PDFs/RRC3-user-manual.pdf) sayfa 2
- [11]Missile Works Corporation. Rocket Recovery Controller 3 User Manual. (Şubat, 2025) Erişim Adresi: [https://www.apogeerockets.com/downloads/PDFs/RRC3-user-manual.pdf] (https://www.apogeerockets.com/downloads/PDFs/RRC3-user-manual.pdf) sayfa 6
- [12] Missile Works Corporation. Rocket Recovery Controller 3 User Manual. (Şubat, 2025) Erişim Adresi: [https://www.apogeerockets.com/downloads/PDFs/RRC3-user-manual.pdf] (https://www.apogeerockets.com/downloads/PDFs/RRC3-user-manual.pdf) sayfa 2
- [13] Bosch Sensortec, BNO055 Intelligent 9-Axis Absolute Orientation Sensor Datasheet, pp. 23-24. [Çevrimiçi]. (2025, Mart). Erişim Adresi: [https://cdn-shop.adafruit.com/datasheets/BST_BNO055_DS000_12.pdf] (https://cdn-shop.adafruit.com/datasheets/BST_BNO055_DS000_12.pdf)
- [14] Espressif Systems, ESP32-S3-WROOM-1 & ESP32-S3-WROOM-1U Datasheet, pp. 17-19. [Çevrimiçi]. (2025, Mart). Erişim Adresi: [https://www.espressif.com/sites/default/files/documentation/esp32-s3-wroom-1_wroom-1u_datasheet_en.pdf]
- [15] Digi International, XBee/XBee-PRO SX RF Modules Datasheet, pp. 1-3. [Çevrimiçi]. (2025, Mart). Erişim Adresi: [https://www.mouser.com/datasheet/2/111/ds-xbee-xbeepro-sx-modules-1016961.pdf] (https://www.mouser.com/datasheet/2/111/ds-xbee-xbeepro-sx-modules-1016961.pdf)
- [16] Infineon Technologies, DPS310 Digital Barometric Pressure Sensor Datasheet, p. 13. [Çevrimiçi]. (2025, Mart). Erişim Adresi: [https://www.infineon.com/dgdl/Infineon-DPS310-DataSheet-v01_02-EN.pdf?fileId=5546d462576f34750157750826c42242] (https://www.infineon.com/dgdl/Infineon-DPS310-DataSheet-v01_02-EN.pdf?fileId=5546d462576f34750157750826c42242)

# Referanslar

- [17] A. Becker, Kalman Filter Summary, [Çevrimiçi]. (2025, Mart). Erişim Adresi: [https://www.kalmanfilter.net/multiSummary.html]
- [18] Missile Works Corporation. Rocket Recovery Controller 3 User Manual. (Şubat, 2025) Erişim Adresi: [https://www.apogeerockets.com/downloads/PDFs/RRC3-user-manual.pdf] (https://www.apogeerockets.com/downloads/PDFs/RRC3-user-manual.pdf) sayfa 4
- [19] Missile Works Corporation. Rocket Recovery Controller 3 User Manual. (Şubat, 2025) Erişim Adresi: [https://www.apogeerockets.com/downloads/PDFs/RRC3-user-manual.pdf] (https://www.apogeerockets.com/downloads/PDFs/RRC3-user-manual.pdf) sayfa 11
- [20] Missile Works Corporation. Rocket Recovery Controller 3 User Manual. (Şubat, 2025) Erişim Adresi: [https://www.apogeerockets.com/downloads/PDFs/RRC3-user-manual.pdf] (https://www.apogeerockets.com/downloads/PDFs/RRC3-user-manual.pdf) sayfa 24
- [21]Missile Works Corporation. Rocket Recovery Controller 3 User Manual. (Şubat, 2025) Erişim Adresi: [https://www.apogeerockets.com/downloads/PDFs/RRC3-user-manual.pdf] (https://www.apogeerockets.com/downloads/PDFs/RRC3-user-manual.pdf) sayfa 13
5 Şubat 2025 Çarşamba | 2025 TEKNOFEST ROKET YARIŞMASI ÖN TASARIM RAPORU
78

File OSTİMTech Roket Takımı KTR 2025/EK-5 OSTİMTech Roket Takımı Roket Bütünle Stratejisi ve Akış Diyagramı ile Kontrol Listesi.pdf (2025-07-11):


# TEKNOFEST Orta İrtifa Roket Yarışması Kritik Tasarım Raporu

EK-5

# Roket Bütünleme Stratejisi

Ve

# Akış Diyagramı ile Kontrol Listesi

## ANKARA Mayıs 2025

ROKET MONTAJ STRATEJİSİ:

Roketin entegrasyonu belirli bir sıraya göre gerçekleştirilecek olup bu sıralama, hem montaj kolaylığı hem de alt sistemlerin birbirine zarar vermeden doğru biçimde yerleştirilmesi esas alınarak planlanmıştır.
Roket montajı esnasında montajı yapacak olan takım iki ekibe bölünmüştür. Birinci ekip yük gövdesi ve elemanlarının montajını yaparken ikinci ekip motor gövdesi elemanlarının ve motorun montajını gerçekleştirecektir. Roket montaj basamakları aşağıda görseller ve metinlerle açıklanmıştır.

1.Yük Gövdesi ve Bileşenlerinin Montajı


Birinci aviyonik balket, aviyonik balket montajında balketler arası mesafeyi ayarlamak için tasarlayıp ürettiğimiz aparata (kırmızı) yerleştirilmiştir. İki adet M5 saplama, balket üzerindeki vida yuvalarında ilerletilmiştir.


Balket üzerindeki deliklerden ilerlerleyen saplamalara aviyonik kart tutucu plaka (beyaz), üzerindeki deliklerden geçirilerek yerleştirilmiştir.


İkinci aviyonik balket aparatın diğer bölmesine yerleştirilerek saplamalar ilerletilmeye devam edilmiştir. İkinci balket üzerindeki vida deliklerine saplamalar denk getirilmiştir. Böylece aviyonik taşıyıcı plaka aviyonik balketler arasına yerleştirilmiş olup her iki balket arasındaki mesafe doğru bir şekilde ayarlanmıştır.

Aviyonik balketler üzerindeki M4 vida yuvalarına EK-3 te belirtilen sıcak gaz üretecine ait klipsler (yeşil) yerleştirilir ve sıkıca montajlanmıştır.


Aviyonik balketler üzerine paraşütlerin ve şok kordonlarının bağlantılarını yapabilmek amacıyla birer adet M8 dövme çelik mapalar montajlanmıştır.


Klipsler, mapalar ve kart tutucu aviyonik balketler üzerinde montajlandıktan sonra mapalara sürüklenme paraşütü şok kordonu karabinalar ve fırdöndüler aracılığıyla bağlanmıştır ve bütün olarak balketler yük gövdesine yukarıdan sürülerek yük gövdesi içine yerleştirilmiştir. Gövdeye yerleştirilen aviyonik balket montajı vidalanmadan önce ana paraşüt şok kordonu gövdenin içinden geçirilerek alttaki balketin üzerindeki mapa ve şok kordonuna bağlı karabina aracılığıyla bağlanmıştır. Aviyonik balketler gövdeye 6 adet M6 civata ile sıkıca sabitlenmiştir.


Görev yükü ve paraşütler yerleştirilmeden önce sıcak gaz üreteci kapsüllerinin (turuncu) montajını engellememek için kapsüller öncesinde montajlanmış olan klipslere takılarak aktifleştirme için kullanılcak kablolar balket üzerindeki delikten geçirilmiştir.


Dışarıda bütünlenmiş olan görev yükü bir bütün olarak sıcak gaz üretici kapsüllerinin üzerine yerleştirilmiştir. Görev yükünün üzerine, ayrılma esnasında sıcak gaz üreticinin oluşturduğu ısı enerjisinden paraşütleri korumak için yanmaz kumaş serilmiştir.


Görev yükü üzerindeki mapaya görev yükü paraşütünün (turuncu-siyah) mapa, fırdöndü ve karabina ile bağlantıları yapılarak görev yükü paraşütü gövde içerisine yerleştirilmiştir.


Birinci ayrılma esnasında roketin kontrollü düşüşünü sağlayacak olan sürüklenme paraşütü (kırmızı-siyah), görev yükü paraşütü üzerine yerleştirilmiştir.


Burun konisi içerisindeki mapaya birinci ayrılma esnasında patlamanın enerjisini sönümleyip burun konisini gövdeye bağlı tutacak şok kordonunun bağlantısı yapılır. Burun konisi omuzluğu gövde içerisine sıkı geçme tekniğiyle montajlanır.


Roketin ikinci ayrılma esnasında yere inişini sağlayacak olan ana paraşüt (yeşil-siyah) alt aviyonik balket üzerindeki mapaya karabina ve fırdöndü ile bağlanmıştır. İkinci ayrılma esnasında patlama enerjisini sönümlemek amacıyla şok kordonu yine alt aviyonik balket üzerindeki mapaya bağlanmıştır. Sıcak gaz üreticilerin oluşturduğu ısı enerjisinden ana paraşütün etkilenmemesi için paraşüt altına yanmaz kumaş serilmiştir.

Aviyonik kart, kart taşıyıcı plakaya plaka üzerindeki deliklerden yalıtkan olması sebebiyle M3 plastik vidalarla sabitlenmiştir.


Aviyonik kart taşıyıcı plaka, plaka tutucuya üzerinde bulunan kızaklı sistem sayesinde sürülerek yerleştirilmiştir.


Aviyonik kapağı (turuncu) gövdeye vidalandıktan sonra rampada hakem altimetresini yerleştirmek için hakem altimetresine ait bölme kapağı açık tutulmuştur.


Roketi fırlatma rampasına yerleştirmek için kullanılacak olan railbuttonlar EK-2 de belirtilen fırlatma rampası özelliklerine göre M4 havşa başlı civata ile alt aviyonik balkete vidalanmıştır. Rampada aviyonik kapağa ve hakem altimetresine erişimi sağlayabilmek için railbutton kapağın arkasında kalacak şekilde iki vida deliği arasına yerleştirilmiştir.

2.Motor Gövdesi ve Bileşenleri Montajı


Roket montaj operasyonunda motor gövdesi ve motor montajını yapacak olan ekip montaja kanatçıklardan başlanmıştır. Kanatçıklar, kanatçık balketi üzerindeki iki adet M5 vida yuvalarına montajlanmıştır.


Kanatçık montajı, 4 kanatçık için de yapılarak kanatçıklar bir araya getirilmiştir. Kanatçıklar aralarındaki açı 90° olacak şekilde montajlanmıştır.


Kanatçık balketleri motor gövdesi üzerindeki 4 adet kanatçık yarığına denk getirilip ileri doğru sürülmüştür.

Kanatçık balketleri gövde üzerindeki deliklere M5 civatalar ile sabitlenmiştir. Böylece kanatçıkların montajı bitmiş olup bir sonraki komponente geçilmiştir.

Motor merkezleme halkası motor gövdesinin üst kısmından içeri doğru sürülerek vida delikleri denk getirilmiştir.


Motor merkezleme halkası gövdeye 4 adet M5 civata ile montajlanmıştır.

Motor merkezleme halkası üzerine EK-2 de belirtilen şekilde M4 havşa başlı civata ile railbutton takılmıştır.

Motor üst balketi entegrasyon gövdesi içerisine vida delikleri denk gelecek şekilde motor gövdesi dışında yerleştirilmiştir.


Motor üst balketi entegrason gövdesi ile birlikte motor gövdesinin üst kısmına yerleştirilerek vida delikleri denk getirilmiştir. Böylece motor üst balketi, entegrasyon gövdesi ve yük gövdesi üzerindeki vida delikleri denk getirilmiş olunmaktadır.

Motor üst balketi motor gövdesine 6 adet M5 civata ile montajlanmıştır.


Motor şartnamade belirtildiği şekilde en son montajlanır. Motor, motor gövdesine kanatçıkların bulunduğu kısımdan sürülmüştür. Bu esnada motor merkezleme halkası ve kanatçık balketlerinin ortasındaki yuvalar motorun sabit kalmasını sağlamaktadır.


Motor, gövdeye alt kısımdan sürüldükten sonra motor üst balketine dayanmıştır. Burada motor üst yüzeyi ile balket alt yüzeyinin paralel kalmasına, motor yüzeyi ile balket yüzeyinin tam temas etmesine özen gösterilmiştir.

Motor yerleştirildikten sonra motoru sabitleyecek olan civata ile balket arasındaki temas yüzeyini artırmak amacıyla pul (kırmızı) kullanılmıştır.

Pul üzerinden motor 3/8” civata ile motor üst balketine sabitlenmiştir.


Motor montajından sonra motor arka kapağı motorun nozül kısmına yerleştirilmiştir.

Motor arka kapağı gövdeye 4 adet M5 civata ile sabitlenmiştir.

Yük gövdesi ve motor gövdesi, entegrasyon gövdesi (sarı) yardımıyla birbirine sıkı geçme tekniğiyle montajlanmıştır.


Rampaya yerleştirilen rokete EK-1 de belirtilen hakem altimetresi, kapakçık üzerindeki altimetre yuvasına yerleştirilmiştir. M3 civatalar ile kapak kapatılıp roket ateşlemeye hazır hale getirilmiştir.

YÜK GÖVDESİ MONTAJ KOKNTROL LİSTESİ

Sıra No. | Kontrol Edilecek Madde | Kontrol edilme durumu
1 | Aviyonik balket üzerine barut tüpü klipslerinin civatasını ve mapaları sıkıca montajladın mı?
2 | Aviyonil balketleri saplama ile montajlarken balkedler arası mesafeyi kontrol ettin mi?
3 | Railbutton deliği olan balketi roketin alt kısmına gelecek şekilde yerleştirdin mi?

4 Barut tüpünü takarken kabloları uygun deliklerden geçirdin mi?

5 | Paraşüt iplerini ve şok kordonlarını aviyonik balket üzerindeki mapaya karabina ile taktın mı?
6 | Görev yükünü yerleştirdikten sonra üzerine yanmaz kumaş serdin mi?
7 | Önce görev yükü paraşütünü sonra sürükleme paraşütünü yerleştirdin mi?

8 Şok kordonunu burun konisi mapasına bağladın mı?

9 Alt aviyonik balkede railbuttonu bağladın mı?

10 Ana paraşüt iplerini ve şok kordonunu alt aviyonik balkedin | mapasına karabina ile bağladın mı?
11 Aviyonik kart üzerindeki anten aşağı yönlü olcak şekilde kızaklara | yerleştirdin mi?

MOTOR GÖVDESİ MONTAJ KONTROL LİSTESİ

Sıra No. | Kontrol Edilecek Madde | Kontrol edilme durumu
1 | Kanatçıkları kanatçık balkedine yüzeyleri tam temas edecek şekilde paralel maontajladın mı?

2 Kanatçıkları bütünledikten sonra gövdeye sıkıca sabitledin mi?

3 | Merkezleme halkasını gövdeye üstten sürerek railbutton deliği denk gelecek şekilde montajladın mı?
4 | Motor üst balkedini entegrasyon gövdesine yerleştirirken vida deliklerini denk getirdin mi?
5 | Entegrasyon gövdesini motor üst balkediyle birlikte motor gövdesine sıkıca sabitledin mi?
6 | Motoru gövdenin alt kısmından sürüp motor vidası ile üst balkede bağlarken vida ile balked arasına pul koydun mu?

7 Motor arka kapağını sıkıca gövdeye montajladın mı?

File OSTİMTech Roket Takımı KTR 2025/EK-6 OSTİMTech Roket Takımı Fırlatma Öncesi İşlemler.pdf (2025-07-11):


# TEKNOFEST Orta İrtifa Roket Yarışması Kritik Tasarım Raporu

EK-6

# FIRLATMA ÖNCESİ İŞLEMLER

## ANKARA Mayıs 2025

Montaj günü montajı yapılan roketin uçuş öncesi son hazırlıklarının yapılmasını kapsayan işlemlere Fırlatma Öncesi İşlemler denir. Fırlatma öncesi kontrollerde mekanik ekip roketin rampaya taşınmasından ve yerleştirilmesinden sorumludur.

Aviyonik ekip sistemin pillerinin doluluğunu kontrol eder, gerek duyulması halinde dolu pillerle değişim yapılır.

Roket fırlatma rampasına burun, gövde ve kuyruk kısımlarından taşınarak getirilir. Taşıma esnasında roketin bel vermemesine dikkat edilir. Taşıma ve rampaya yerleştirme esnasında roketin sıkı geçmeyle birleştirilen parçaların de-monte olmamasına dikkat edilir.


Roketin rampaya yerleştirilmesi esnasında ilk olarak alt railbutton (kırmızı) rampa üzerindeki kanallardan geçirilir. Rampaya yerleştirilme esnasında kanatçıkların rampaya temas etmesini önlemek için railbutton iki kanatçığın ortasında hizalanmıştır.


Roket ileri sürülerek ikinci railbutton rampadaki kanallara oturtulur. İkinci railbutton rampaya denk gelmezse roket entegrasyon gövdesi etrafında döndürülerek railbutton rampaya denk getirilir.


Roket üzerindeki railbuttonlar rampaya yerleştirildikten sonra roket rampanın sonuna kadar sürülür. Hakem altimetresi montajına geçilir.


Teknofest tarafından verilecek 1 gün öncesinden şarj edilen hakem altimetresinin montajı aviyonik ekibin sorumluluğundadır. Hakem altimetresi roket rampaya yerleştikten sonra aviyonik kapak üzerindeki yuvasına yapılır. Altimetre yerleştirildikten sonra altimetrenin yan bölgelerindeki iki adet delikten M4 civatalarla sabitlenir. Özgün ve Ticari UKB’ ler anahtarlandıktan sonra en son hakem altimetresi anahtarlaması yapılır.


Hakem altimetresi yuvası kapağı kapatılır ve M2 civatalar dört köşeden sıkılır. Böylece hakem altimetresi montajı tamamlanmış olur.


Rampa dikleştirilerek roket atış pozisyonuna getirilir.

1 Roketin taşınması esnasında sıkı geçme ile montajlanan bölgelerin montajı | sağlam kaldı mı?
2 Roket rampaya yerleştirme esnasında railbuttonların aynı hizada olduğunu | kontrol ettin mi?

3 Aviyonik kart pillerinin doluluğu kontrol edildi mi?

4 YAGİ Anten bağlantısı doğru yapıldı mı?

5 Yer kontrol istasyonu arayüzü ile hakem istasyonunu bağlantısı doğru yapıldı | mı?

6 Roketin anahtarlaması sonrası ilk veriler geldi mi?

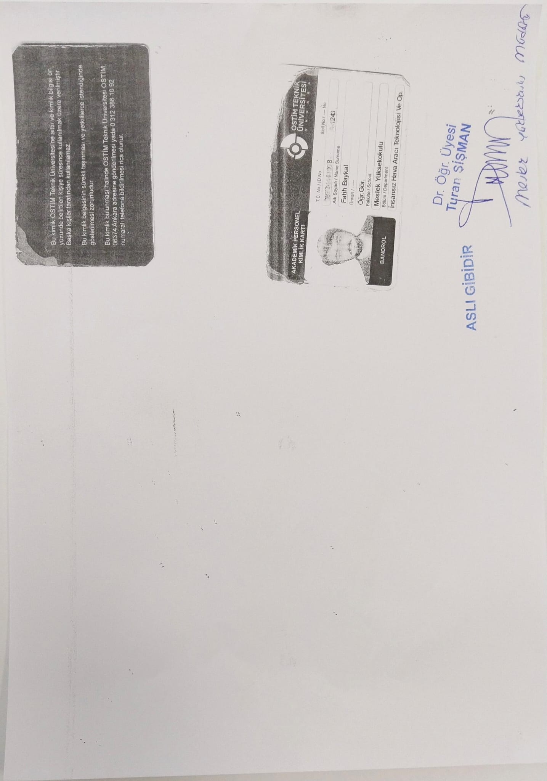
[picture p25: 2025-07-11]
OSTİMTech Roket Takımı KTR 2025/Fatih Baykal Öpretim Görevlisi.jpg

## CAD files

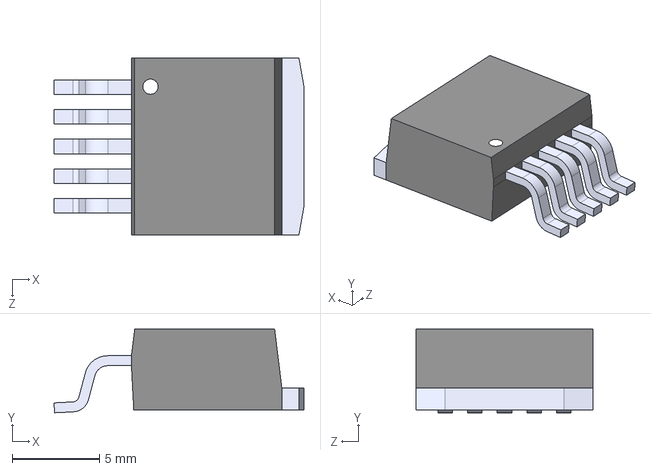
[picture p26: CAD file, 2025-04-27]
Semih PCB Tasarımı/LM2576S-3.3_NOPB.step
14.4 x 4.80 x 10.2 mm

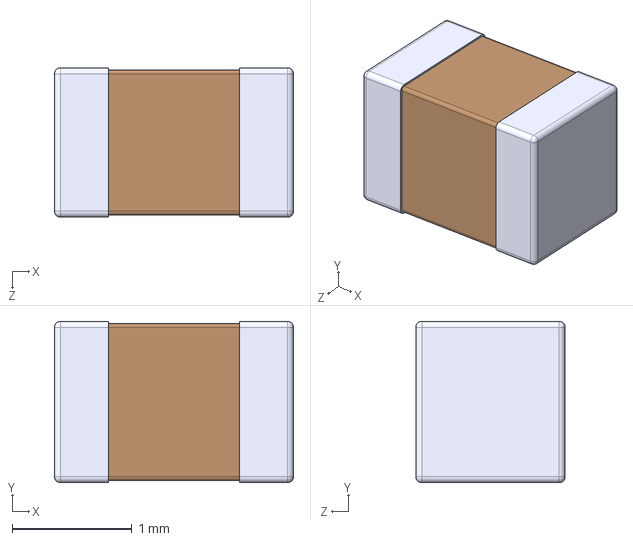
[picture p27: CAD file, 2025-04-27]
Semih PCB Tasarımı/GRM21BR61C106KE15K.step
2.00 x 1.35 x 1.25 mm

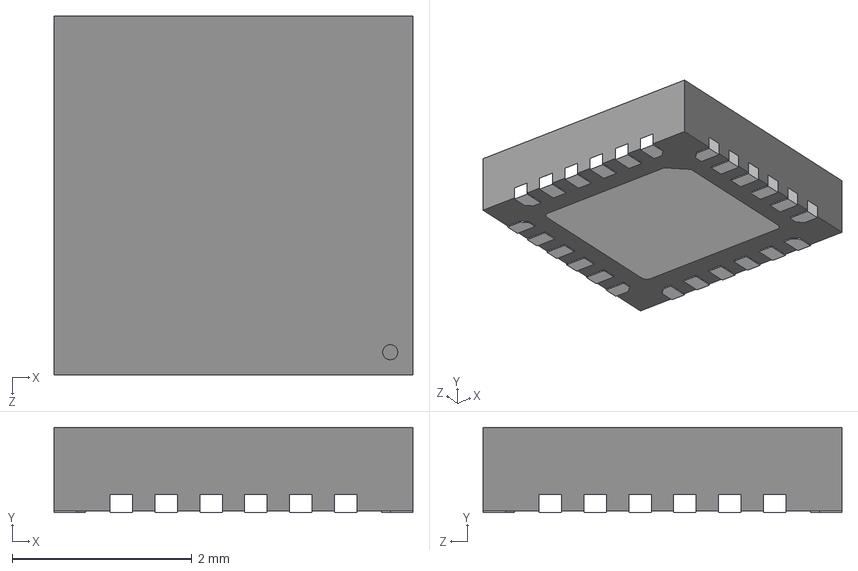
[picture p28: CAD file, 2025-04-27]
Semih PCB Tasarımı/MPU-6050.step
4.00 x 0.95 x 4.00 mm

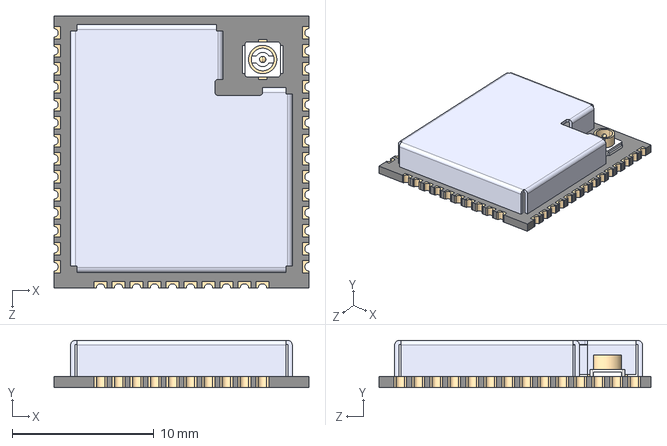
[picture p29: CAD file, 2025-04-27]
Semih PCB Tasarımı/ESP32-WROOM-32UE.step
18.0 x 3.35 x 19.2 mm

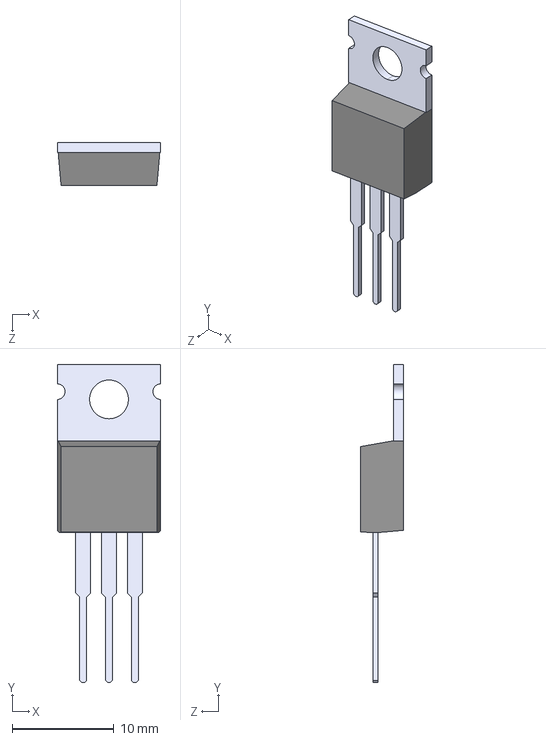
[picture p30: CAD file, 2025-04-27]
Semih PCB Tasarımı/IRFZ44N.step
10.2 x 31.2 x 4.19 mm

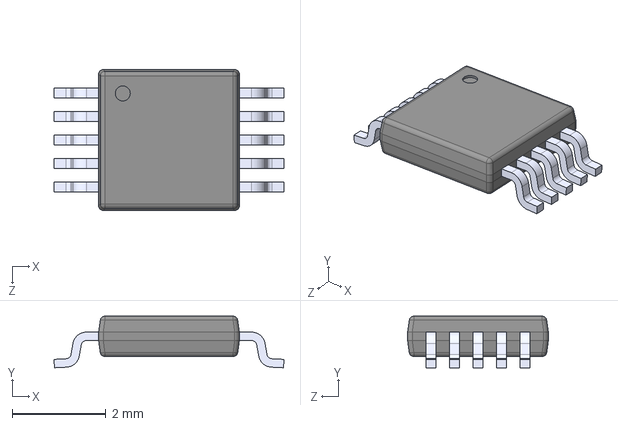
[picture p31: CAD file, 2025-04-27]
Semih PCB Tasarımı/LTC4441IMSE_PBF.step
4.90 x 1.10 x 3.00 mm

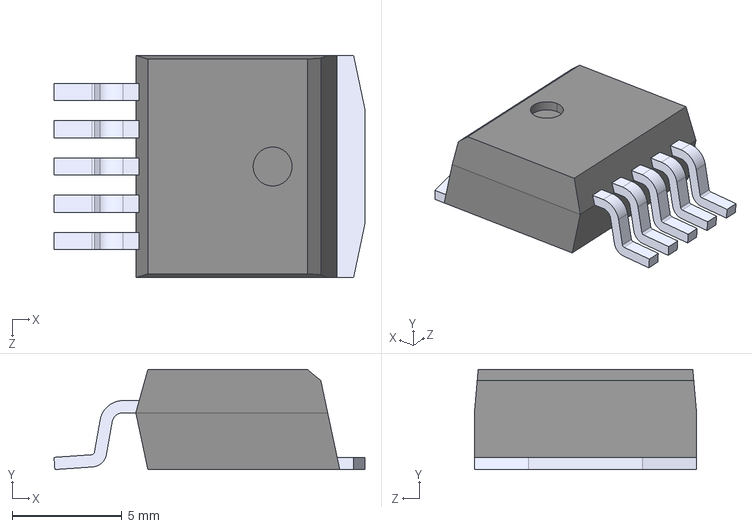
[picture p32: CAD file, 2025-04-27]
Semih PCB Tasarımı/LM2596DSADJG.step
14.2 x 4.57 x 10.1 mm

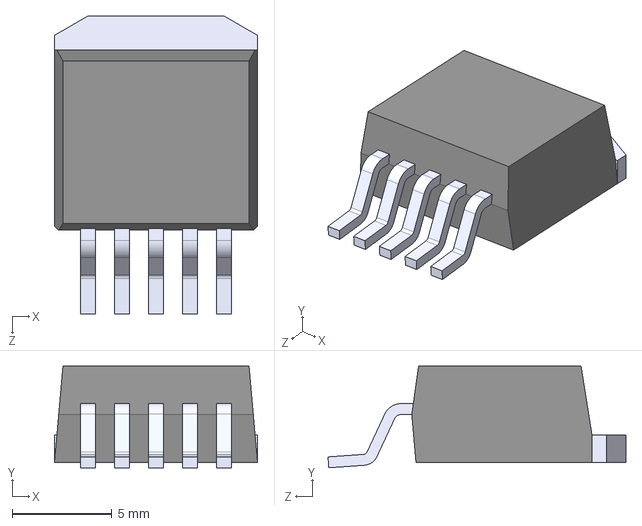
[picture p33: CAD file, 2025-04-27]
Semih PCB Tasarımı/LM2576-3.3WU.step
10.2 x 5.08 x 14.9 mm

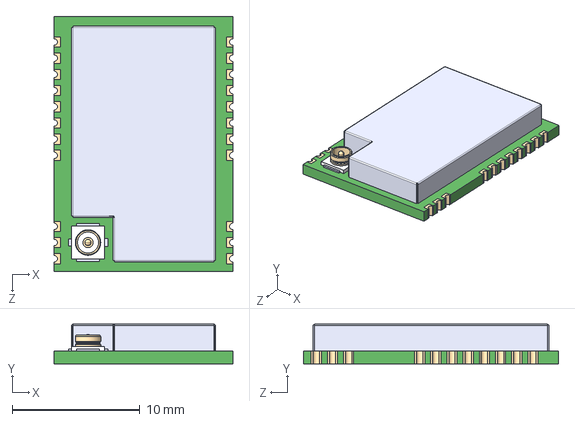
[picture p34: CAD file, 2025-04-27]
Semih PCB Tasarımı/E22-900M22S.step
14.0 x 3.10 x 20.0 mm

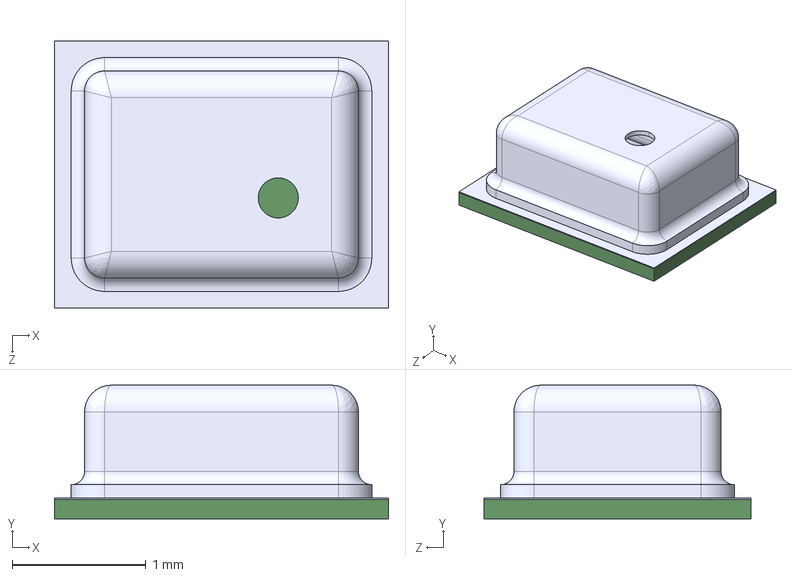
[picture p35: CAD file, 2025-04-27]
Semih PCB Tasarımı/BMP280.step
2.50 x 1.00 x 2.00 mm

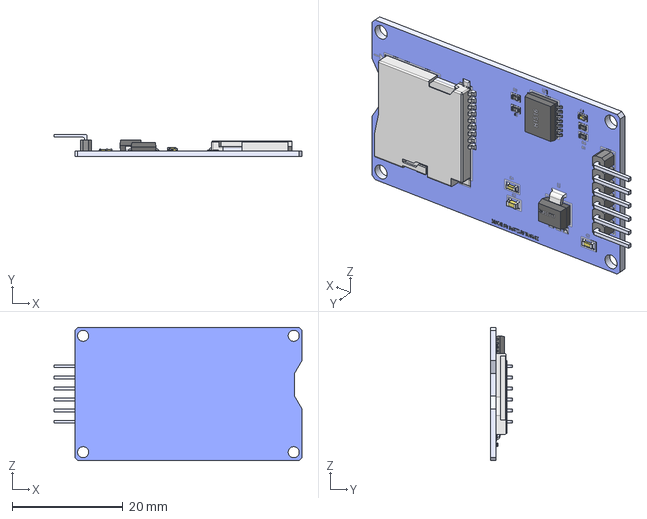
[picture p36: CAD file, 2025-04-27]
Semih PCB Tasarımı/leitor microsd.step
44.7 x 4.00 x 24.0 mm

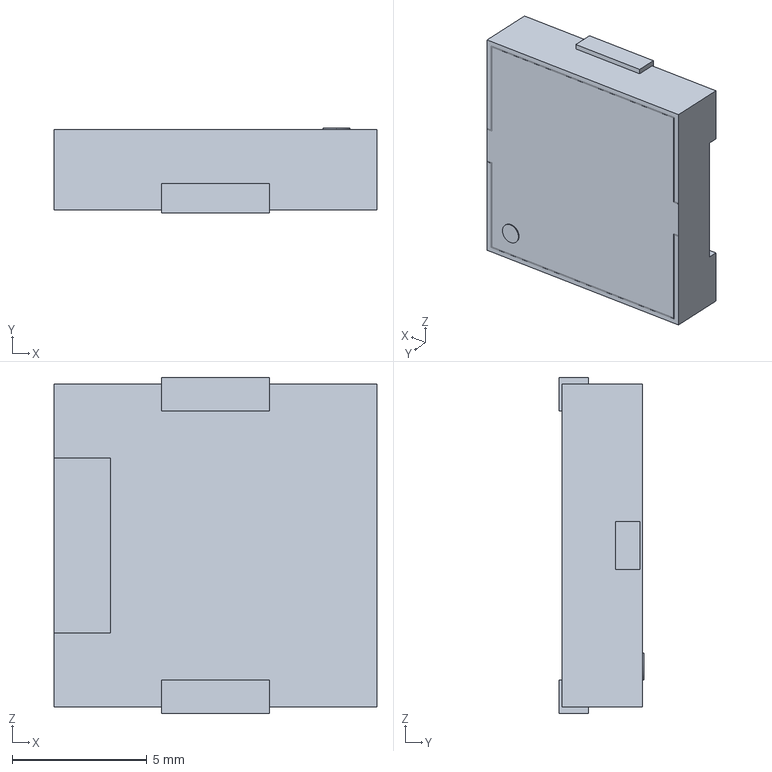
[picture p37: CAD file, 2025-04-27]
Semih PCB Tasarımı/KMTG1203.step
12.0 x 3.15 x 12.5 mm

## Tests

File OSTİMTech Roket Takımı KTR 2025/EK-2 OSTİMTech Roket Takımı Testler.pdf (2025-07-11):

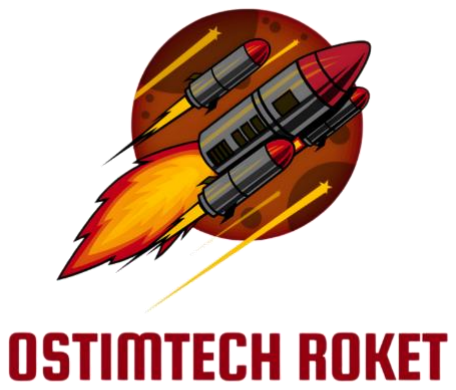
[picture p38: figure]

# TEKNOFEST

# Orta İrtifa Roket Yarışması

# Kritik Tasarım Raporu

EK-2

# TEST SONUÇLARI RAPORU

## ANKARA Mayıs 2025

İÇİNDEKİLER

## a. Aviyonik Testleri

## 1. Algoritma Testleri

Asansör Testi:

15.05.2025 tarihinde gerçekleştirilmiştir.

Amaç

Algoritmanın ilk amaçlarından birisi olan hız negatif olduğunda, dolayısıyla roketin çıkabileceği en yüksek noktadan düşmeye başladığında, işlevinin yerine getirilmesi test edilmektedir.

Test Düzeneği

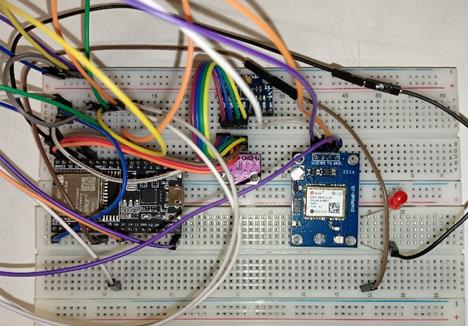
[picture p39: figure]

Roketi simüle etmek için breadboard üzerine kurulmuş prototip bir devre kullanılmıştır. Bu devrede basınç sensörü BMP280, IMU sensörü MPU6050, geliştirme kartı ESP32 Devkitc V4 ve kırmızı led kullanılmıştır. Devrede gözüken GPS modülü NEO M8N bu test için kullanılmamıştır.

Yöntem

Asansörün yukarı ve aşağı yönlü hareketi sırasındaki hızı kullanılarak roketin apogee’ye ulaştığındaki hız değişikliği algılanarak simüle edilmiştir. Simülasyona göre roket apogee’ye ulaştığını algılayabilmek için kırmızı ışığın yakılması kullanılmıştır.

Testin Fotoğrafları

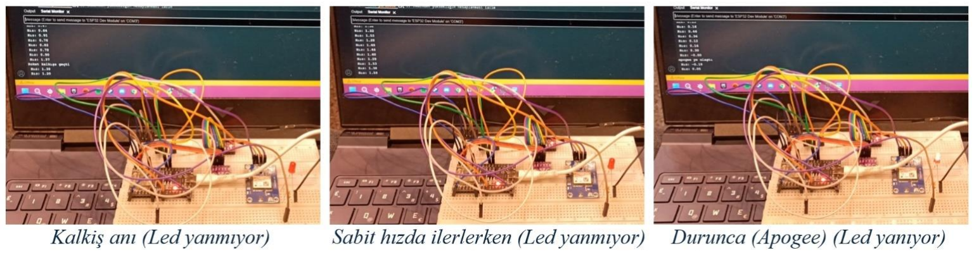
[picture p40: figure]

Testten Elde Edilen Veriler

Hesaplanan hız 1 m/s (metre/saniye) ‘nin üzerine çıktığında kalkışa geçtiği, kalkışa geçtikten sonra hız 0 m/s ‘nin altına düştüğünde apogee’ye ulaştığı tespit edilmiştir.Bu eşik değerler rokette farklı olacaktır, bu deney için ölçek değiştirilmiştir.

Verilerin Analizi ve Sonuçlar

Elde edilen verilere göre roketin hız verisine bakılarak kalkış yapıldığını algılayabileceği ve yine hız verilerine bakılarak apogee’ye ulaştığını algılayabilerceği kanıtlanmıştır.Daha sonraki yapılabilecek deneylerde bu çalışmanın limitleri sorgulanmalı, ani değişimlerde sistem tepkileri incelenmelidir ancak şimdilik algoritmanın kalkış ve sürüklenme paraşütü aşamalarında çalışabilirliği desteklenmiştir.

Vakum Pompası Testi:

07.05.2025 tarihinde gerçekleştirilmiştir.
Amaç

Algoritmanın istenilen yüksekliğe geldiğinde ana paraşütü açabildiğini kontrol etmek için vakum pompası testi yapılmıştır.

Test Düzeneği

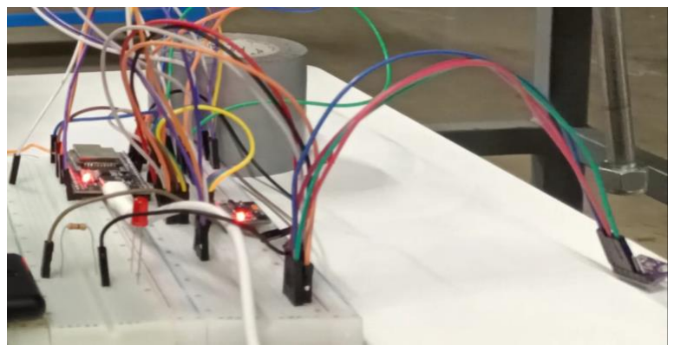
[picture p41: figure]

Roketi simüle etmek için breadboard üzerine kurulmuş prototip bir devre kullanılmıştır. Bu devrede basınç sensörü BMP280, IMU sensörü MPU6050, geliştirme kartı ESP32 Devkitc V4 ve kırmızı led kullanılmıştır.

Yöntem

Yüksekliği ölçmek için kullandığımız sensörün yüksekliği basınç değişimleriyle ölçmesinden yararlandık. Vakum pompasından gelen boru basınç sensörünün üzerine tutulduktan sonra, düşen basıncın etkisi ile algılanan yükseklik artmıştır. Ardından vakum pompasından gelen

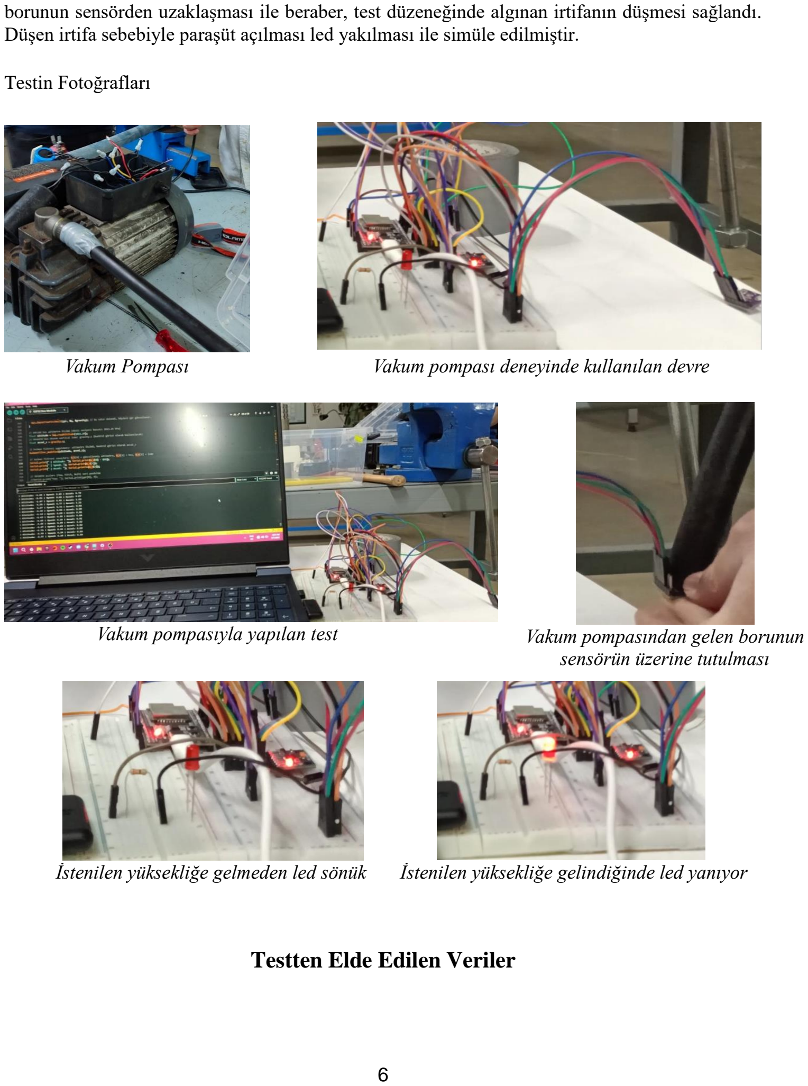
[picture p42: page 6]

borunun sensörden uzaklaşması ile beraber, test düzeneğinde algınan irtifanın düşmesi sağlandı. Düşen irtifa sebebiyle paraşüt açılması led yakılması ile simüle edilmiştir.

Testin Fotoğrafları

Testten Elde Edilen Veriler

Vakum Pompası | Vakum pompası deneyinde kullanılan devre
Vakum pompasıyla yapılan test | Vakum pompasından gelen borunun sensörün üzerine tutulması
İstenilen yüksekliğe gelmeden led sönük | İstenilen yüksekliğe gelindiğinde led yanıyor

Bu test için paraşütü tetikleyecek değer 3000 metre olarak ayarlandı. Sensor vakumlandığında yükseklik 8000 metreye kadar yükseldi ve normal basınca dönerken 3000 metrenin altına düştüğü anda sinyal gönderilerek led yakıldı.

Verilerin Analizi ve Sonuçlar

Bu testte algoritmanın simülasyona göre istenilen irtifaya ulaştığını algılayabildiği kırmızı ledin yanması sayesinde kanıtlandı. Ayrıca test düzeneğinde elde edilen irtifadan yola çıkılarak, roketin potansiyel düşüşünden çok daha hızlı azalan yüksekliklerde bile sistemin tetiklenebileceği gözlemlendi.

## 2. Haberleşme Testleri

Amaç

Roketin yer istasyonu ile haberleşmesini simüle etmek için Haberleşme Testleri 13.05.2025 tarihinde gerçekleştirilmiştir.

Test Düzeneği

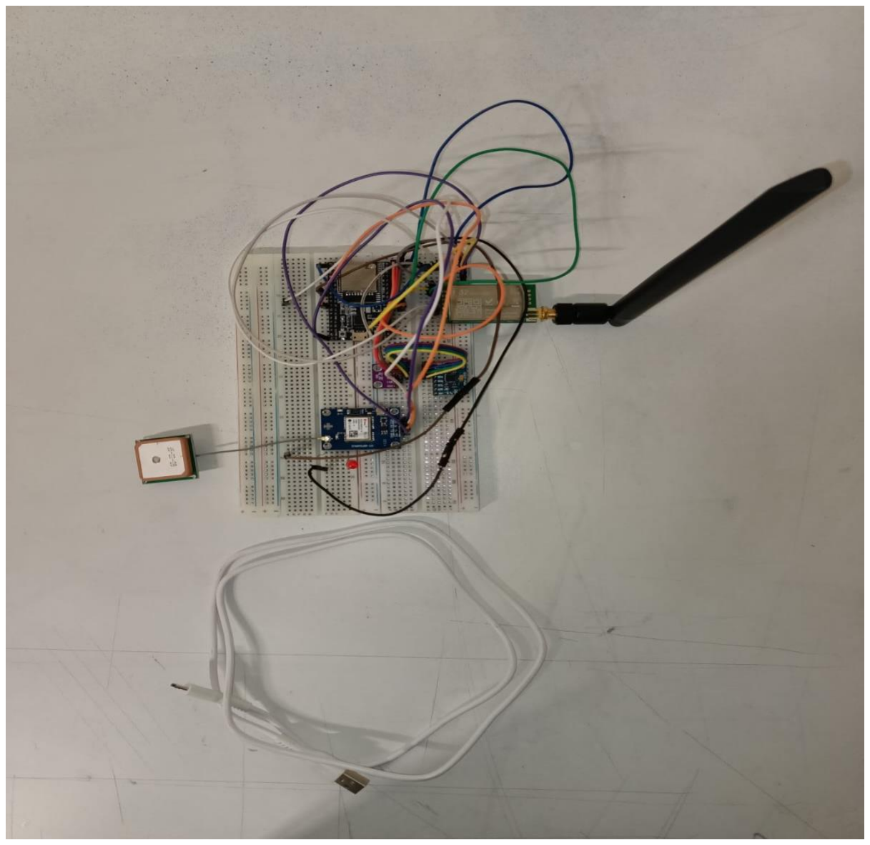
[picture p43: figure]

Roketi simüle etmek için breadboard üzerine kurulmuş prototip bir devre kullanılmıştır. Bu devrede basınç sensörü BMP280, IMU sensörü MPU6050, GPS modülü NEO M8N, haberleşme modülü LoRa E32 433T30D ve Özgün UKB'de kullanılacak olan ESP32 S3 WROOM 1U mikrodenetleyicisi ile aynı mimariye sahip olan geliştirme kartı ESP32 Devkitc V4 kullanılmıştır. Haberleşme modülüne 433 MHz 4 dBi kazançlı dikey polarizasyonlu SMA anten takılmıştır.

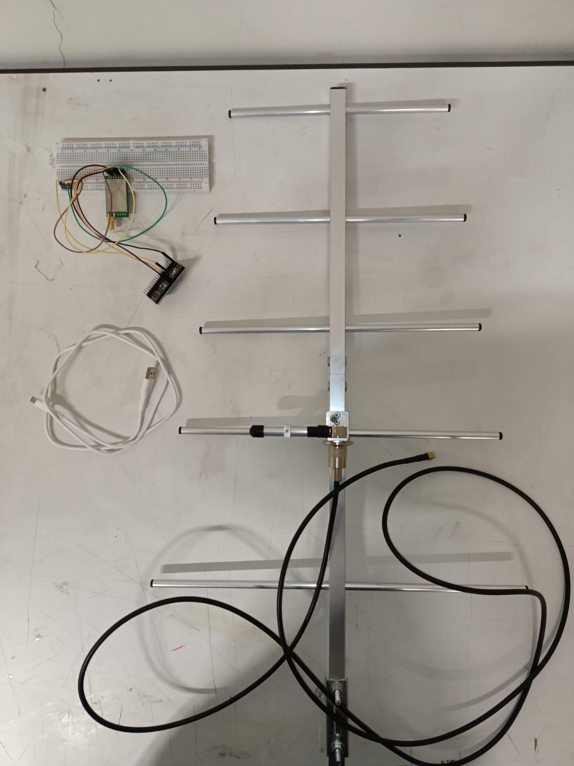
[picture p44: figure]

Yer istasyonunu simüle etmek için ESP32 Devkitc V4 geliştirme kartı ve haberleşme modülü LoRa E32 433T30D breadboard üzerinden bağlanmıştır. Bu sistemdeki haberleşme modülüne 12 dBi kazançlı 2,5 metre RG-58 kablo uzantılı 433 MHz Yagi anten takılmıştır.

Yöntem

EK-7 Hakem Yer İstasyonu dokümanında roketten yer istasyonuna iletilebilecek olan verilerden Takım ID, Paket Sayacı, İrtifa, Roket GPS İrtifa, Roket Enlem, Roket Boylam, İvme X, İvme Y, İvme Z ve Durum veri paketleri iki prototip sistem arasında 50 metreyi aşan bir mesafede iletilmiştir. Takım ID 0 ile 255 arasından sabit değer olarak 1 atanmıştır. Paket Sayacı, gönderilen toplam verinin byte cinsinden büyüklüğünü temsil etmektedir ve videoda görülebileceği üzere her veri gönderiminde 31 artmıştır. Bunun sebebi yukarda ifade edilen veri paketlerinin toplamı 31 byte etmektedir(Takım ID = 1, Paket Sayacı = 1, İrtifa = 4, Roket GPS İrtifa = 4, Roket Enlem = 4, Roket Boylam = 4, İvme X = 4, İvme Y = 4, İvme Z = 4, Durum = 1). Kullanılan kodda Paket Sayacı 255 değerini geçtikten sonra mod 255 işlemi yapılıp sayacı arttırmaya devam edecek şekilde tasarlanmıştır. İrtifa verisi BMP280 sensöründen ölçülen basınç değerinin irtifaya çevrilmesiyle elde edilmektedir. GPS İrtifa verisi ise GPS modülü NEO M8N'den elde edilen irtifa verisidir. Roket Enlem ve Roket Boylam verileri yine NEO M8N'den elde edilmektedir. Bu değerler roketin konumunu bulup kurtarma işlemini gerçekleştirmeyi sağlayacaktır. İvme X, İvme Y ve İvme Z verileri IMU sensörü MPU6050'den alınmıştır ve birimleri g (g-force)'dir. Durum verisi roketin birincil ve ikincil paraşütlerinin açılıp açılmama durumlarına göre değişebilen bir değerdir. Herhangi bir paraşüt açılımı için şartlar sağlanmadığından dolayı 0 değeriyle iletilmiştir.

Yer istasyonunu simüle eden alıcı sistemde gelen veriler Serial Monitor ekranında sırasıyla gösterilmiştir.

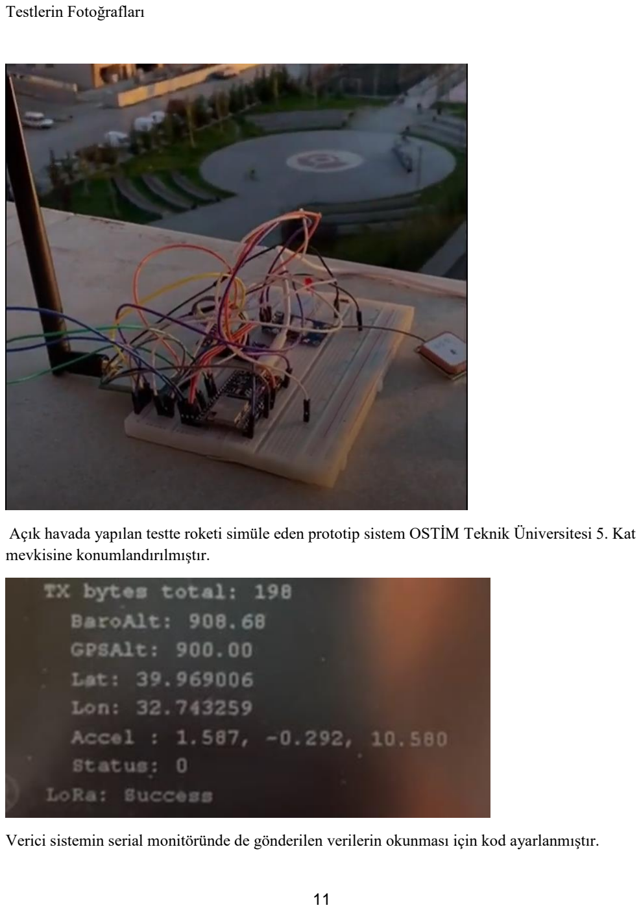
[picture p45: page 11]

Testlerin Fotoğrafları

Açık havada yapılan testte roketi simüle eden prototip sistem OSTİM Teknik Üniversitesi 5. Kat mevkisine konumlandırılmıştır.

Verici sistemin serial monitöründe de gönderilen verilerin okunması için kod ayarlanmıştır.

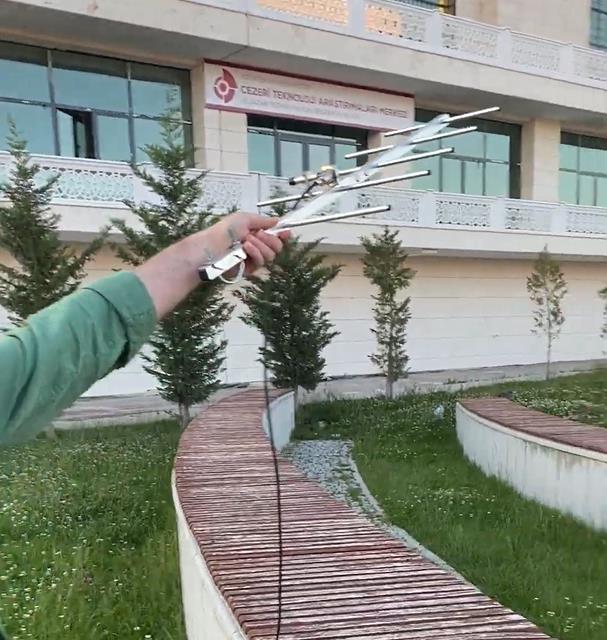
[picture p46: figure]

Yer istasyonunda kullanılacak olan Yagi anten roketi simüle eden prototip sisteme doğru tutulmuştur.

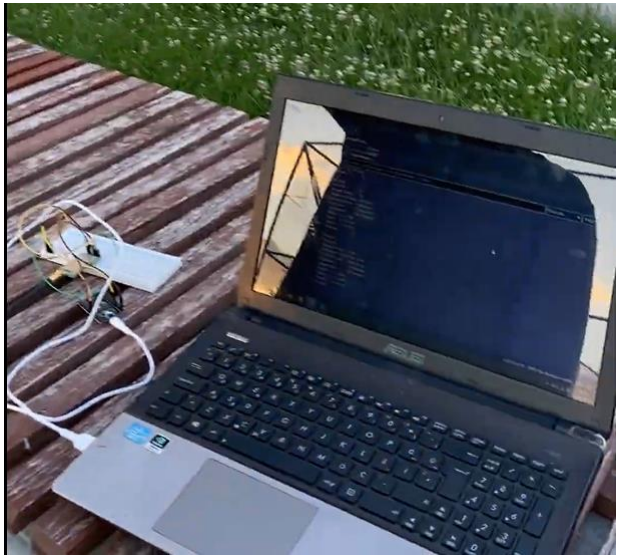
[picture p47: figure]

Yer istasyonunu simüle eden prototip sistem roketi simüle eden sistemden 50 metreyi aşan bir mesafede konumlandırılmıştır.


Alıcı sistemin serial monitöründe veriler eş zamanlı olarak başarılı şekilde aktarılmaktadır.

Testlerden Elde Edilen Veriler

Haberleşmenin kurulan prototip sisteminde başarılı bir şekilde paket kaybı yaşanmadan sağlandığı, haberleşme modülünün Buffer'ı dolmadan gerçekleştiği görülmüştür.

Verilerin Analizi ve Sonuçlar

Roket ile yer istasyonu arasındaki haberleşmenin teoride sağlanabilirliği kanıtlanmıştır. Bu sonuçların desteklenmesi için, deney düzeneğinin daha uzun mesafelerde, daha hızlı gönderilen veri paketleri ile test edilmesi ise gerekli görülmüştür.

## b. Kurtarma Sistemi Testleri

## Amaç

Roketin Ayrılma konseptinin uygun şekilde çalıştığını kontrol etmek için Kurtarma Sistemi Testleri yapılmıştır.

Yöntem

Roketin ayrılma hacmine eş bir hacim oluşturulmuş ve bu hacim farklı miktarlarda basınçlandırılarak testler yapılmış ve sonuçlar analiz edilmiştir. Roket ayrılma hacmini basınçlandırmak için “Teknofest tarafından sağlanan SGU basınç-zaman grafiği” verileri kullanılmıştır. Grafik incelendiğinde zamana bağlı olarak basınç verilerinin azaldığı gözlemlenmiştir. Bu durum başlangıçta düşünülen yüksek hacimli endüstriyel basınçlı gaz kabı kullanılması yönteminden vaz geçerek gerçeğe daha yakın bir sonuç verecek yöntem olan kara barut kullanarak ayrılma yöntemini seçmemizde etkili olmuştur.

Kara barutu basınçlandırma yöntemi olarak seçmemizdeki asıl nedenler SGU benzeri bir basınçlandırma karakteri göstermesi ve literatürde çok çalışılmış bir malzeme olmasıdır. Bu sayede ayrılma işleminin ne kadar basınçta nasıl bir karakteri olacağı hesaplanabilmiştir.

## Teorik Hesaplamalar

Ayrılma için gerekli olan kuvvetin hesabı Ftoplam = Fsürtünme + Fağırlık formülüyle hesaplanmış olsa da sürtünme katsayıları ve ayrılma esnasında gereken hareketten kaynaklı dinamik yükler bilinmediğinden dolayı elde edilen teorik verilerin testlerle doğrulanması ihtiyacı doğmuştur. Testler kapsamında SGU’ ye eşdeğer basınç üretecek Piroteknik Sistem kurgulanmıştır. Hesaplamalar ve testler kolay bulunabilirliği ve literatürde kolayca bilgi edinilebilen “kara barut” kullanılmıştır.

Yöntem olarak Teknofest tarafından sağlanan SGU verileri (Teknofest Roket Yarışması, 2025) kullanılarak basınçlandırılacak roket içi hacmine göre eşdeğer basınç verileri oranlama yöntemiyle elde edilmiştir. Elde edilen basınç verileri her iki ayrılma için 1 ve 2 tüp için hesap edilmiştir. Hesap edilen basınçlar
F= P x A formulüyle kuvvete dönüştürülmüştür.
Ayrılma için gereken kuvvet hesapları;


Teknofest tarafından sağlanan SGU basınç-zaman grafiği (Teknofest Roket Yarışması, 2025)

Testler kapsamında SGU’ye eşdeğer basınç üretecek pirtoteknik sistem kurgulanmıştır. Hesaplamalar ve testler kolay bulunabilirliği ve literatürde kolayca bilgi edinilebilen “kara barut” kullanılmıştır.

Hesaplamalarda ideal gaz formülü “PV=nRT” kullanılmıştır. (Erik Gregersen, The Editors of Encyclopaedia Britannica, t.y.)

R = 8.3144598 × 10⁻² L. bar. K

−1mol⁻¹
T = 3307 K (Mobley, 1997)

Kara Barut Kimyasal Yapısı:
Kara Barut kütlece %75 KNO3, %15 C ve %10 S içerir. (Earl, 1978) Yanma tepkimesi aşağıdaki gibidir.
2KNO3 + 3 C + S ⟶ K2S + N2 +3CO2 (Calvert, 2008) (Calvert, 2008)

Hesaplamalarda 270 g kara barutun yanması sonucunda 4 mol gaz açığa çıkmaktadır.

1.Ayrılma için; Roketten ayrılacak kütle 5 kg olarak hesaplanmıştır. Sürtünme kuvveti dinamometre ile Burun Konisi omuzu ve ana gövde arasında hesaplanmıştır. Hesapların doğrulanması için teste ihtiyaç duyulmuştur.

Basınçlandırılacak hacim:

1.Ayrılma için;

π × (6.25 cm)

2 × (52 cm) = 6.38 L olarak bulunmuştur.

1 adet SGU’ den elde edilecek basınç P1 × V1 = P2 × V2 formülü ile 1.56 bar olarak teorik olarak hesaplanmıştır.

Bu hesaba göre 1 tüple elde edilecek kuvvet
F=P×A formülü ile 0.156MPa × 12271.84mm2=1914 N olarak bulunmuştur.

2 SGU kullanılması durumunda basınç ve kuvvet değerleri ikiye katlanacaktır ve ilk ayrılma için 3828 N olacaktır.

1 SGU kullanıldığı durumda gereken basınca ulaşmak için:
n =

P×V
R ×T

formülü kullanılarak

n =

1.56 Bar × 6.38 L
8.3144598 × 10⁻² L. bar.K⁻¹mol⁻¹ × 3307K

sonucu n= 0.036 mol
1 mol kara barutun yanması sonucu 4 mol gaz açığa çıktığı göz önüne alındığında
(0.036 mol / 4) x 270g/mol = 2.49 g kadar kara barut gerekmektedir.

Yapılan ve “Ayrılma Testleri” başlığı altında sunulan testler incelendiğinde bu miktarın güvenli ve yeterli ayrılmayı sağlamadığı anlaşılmıştır. Bu nedenle aynı işlemler 2 SGU kullanıldığı senaryo için tekrarlanmıştır.

2 SGU kullanıldığı senaryo:

Hacim ve kütle sabit oluğu için
Ulaşılması ön görülen basınç miktarı : 1,56 Bar x 2 = 3.12 Bar
Kullanılması gereken eş değer kara barut miktarı: 2.49 g x 2 = 4.98 g
Hesaplanan yeni barut miktarı için ayrılma testi tekrarlandığında miktarın yeterli olduğu görülmüştür. Güvenli ve yeterli bir 1. Ayrılma için 2 adet SGU kullanılmasına karar verilmiştir.

Testler sonucu alına veriler sonucunda ilk ayrılma için gereken kuvvet F = P x A formülü ile

0.312 MPa × 12271.8 mm² = 3828.8 Nolarak hesaplanmıştır. Kuvvet ön görülenden daha fazla çıkmaktadır bu durumun sızdırmazlık ve dinamik yüklerden kaynaklandığı varsayılmıştır.

2.Ayrılma için:

2.Ayrılma için; Roketten ayrılacak kütle 5 kg olarak hesaplanmıştır. Sürtünme kuvveti dinamometre ile Entegrasyon Gövdesi ve ana gövde arasında hesaplanmıştır. Hesapların doğrulanması için teste ihtiyaç duyulmuştur.

Basınçlandırılacak hacim
π × (6.25 cm)

2 × (62 cm) = 7.608 L
olarak bulunmuştur.

Bu hesaba göre 1 tüple elde edilecek kuvvet F=P×A formülü ile
0.131 MPa × 12271.8 mm² = 1612 Nolarak olarak bulunmuştur.

2 SGU kullanılması durumunda basınç ve kuvvet değerleri ikiye katlanacaktır ve ikinci ayrılma için 3224 N olacaktır.

2 SGU kullanılan senaryo:

Hacim ve kütle sabit oluğu için ulaşılması öngörülen basınç miktarı : 1,31 Bar x 2 = 2,62 Bar Kullanılması gereken eş değer kara barut miktarı: 2.49 g x 2 = 4.98 g
Hesaplanan yeni barut miktarı için ayrılma testi tekrarlandığında miktarın yeterli olduğu görülmüştür. Güvenli ve yeterli bir 2. Ayrılma için 2 adet SGU kullanılmasına karar verilmiştir.

## AYRILMA TESTLERİ

Testler 10.05.2025 tarihinde açık alanda icra edilmiştir.

Kullanılan Malzemeler:


Burun Konisi | Ana Gövde
Motor Gövdesi | Barut Tüpü


Kara Barut | Hassas Terazi | Strafor Köpük
Koli Bandı | Alüminyum Bant | Fünye
Görev Yükü Prototipi | Aviyonik Balket


Ateşleme Kablosu | M6 Civatalar | Peçeteler

## TEST HAZIRLIĞI

Üretilen Barut Tüpleri , Hassas Terazi kullanarak hesaplanan 2,5 g barutla dolduruldu.


2.5g Kara Barut | SGU Parçaları | Kara Barut Yerleştirilme

2.5 g kara barutla doldurulan tüplere barutu bir araya toplaması ve yanmanın etkilerinden plastik tüpleri koruması için Alüminyum bant uygulanmıştır. Alüminyum bantın içine yerleştirilen kara barutun içine fünye yerleştirilmiş ve bir miktar peçete yardımıyla yerine sabitlenmiştir.

Peçete hem fünyeyi sabitlerken hem de barutu sıkıştırarak patlamanın daha hızlı gerçekleşmesini sağlayacaktır. Dolumu yapılan tüpler Balkete m4 cıvata ile monte edildi.


Patlatılmaya Hazır Kara Barut | Montajlanmış SGU Görseli
Montaj işlemi yapılan tüpler açık havadaki test sahasına götürüldü.

Ayrılma Testi 1 :

Roket ana gövdesine monte edilen üst aviyonik balket ve aviyonik balket monte edilmiş olan içine 2.5 gram kara barut dolu 2 adet barut tüpü toplamda 5 g kara barut kullanılmıştır. Bu miktarın roket ayrılma hacmini 3.12 bar basınca ulaştıracağı hesap edilmiştir. Ardından 4 kg kütleye sabit yük konulmuş ve bu yük görev yükü görevi üstlenmiştir.


1.Ayrılma Ana Bileşenler


Açısı Ayarlanmış 1.Ayrılma Düzeneği | Balket Montaj Görseli

Test düzeneği roketin ilk ayrılmada apogee noktasında açılı ayrılma ihtimali düşünülerek test en kötü senaryo için planlanmıştır. Bu nedenle ayrılma düzeneği 30 derece açı olacak şekilde hazırlanmıştır.

Daha gerçekçi bir ayrılma senaryosu için her bir barut tüpüne ayrı ayrı fünye yerleştirilmiştir. Bu fünyeler güç kaynağına bağlıdır güç kaynağından fünyelerin tetiklenmesi neticesinde ayrılmalar gerçekleşmektedir.


1.Ayrılma Test Sonucu Görseli Fünyenin güvenli mesafeden ateşlenmesi sonucunda Burun Konisi ve Faydalı Yükün gövdeyi hızla terk ettiği ve Burun Konisinin daha uzağa gittiği gözlemlenmiştir. Kütleleri göz önüne alındığında bu farkın normal olduğu anlaşılmıştır.

Tek Barut Tüpü Kullanarak yapılan deneme testi

Yukarıdaki işlemler tek Barut Tüpü 2.5 g Kara Barutla tekrar edilmiştir. Teorik hesaplamalarda bu miktarda barutun roket ayrılma hacminin 1.56 bar basınca ulaştıracağı hesaplanmıştır. Açılı testlerde görev yükünün roketi terk etmediği görülmüş yatay bir şekilde test yapıldığında da oluşan ayrılma enerjisi yetersiz bulunmuştur.


1 Tüp Montajlanmış Görseli | Test Sonucu görsel
Her ne kadar tek tüple yatayda ayrılma gerçekleştirilmiş olsa da açılı durumda ayrılma riske girmektedir. Roketin görevi tamamlamasında en kritik aşamalardan biri olan ayrılma işlemi için risk alınmak istenilmediğinden 1. ayrılma için 2 barut tüpü ile 3,12 bar basınç gerekeceği anlaşılmıştır.


Ayrılma Testi 2:

2.Ayrılma Ana Bileşenler

Roket Ana Gövdesi ve Motor Gövdesi, Entegrasyon Gövdesiyle birleştirilip 2 adet barut tüpü balketle birlikte montajlanmıştır.

2.Ayrılma Test Düzeneği Görseli

Test düzeneği Motor Gövdesinin sabit ve Ana Gövdenin hareketli mesnetle düşeyde sabit yatayda serbest olacağı şekilde oluşturulmuştur.

Teorik hesaplar sonucu 2. Ayrılma için 1.31 bar ve 2.62 bar ayrılma basınçlarına göre iki adet test yapılmıştır.

2.Ayrılma Test Sonucu Görseli

2 barut tüpü kullanılarak yapılan ayrılmanın güvenli ve yeterli olduğu anlaşılmıştır 2. Ayrılma için 2.62 bar basınç gerekeceği görülmüştür.

Tek Barut Tüpü İle Yapılan Deneme Testi

2.ayrılma için yapılan testlerdeki sonuçlar tek barut tüpü (2.5 g. kara barut) ve iki adet barut tüpü (5 g. kara barut) kullanılarak yapılan testlerin sonucu karşılaştırmalı incelendiğinde, 2.ayrılma için sağlıklı bir ayrılma olabilmesi için 2 adet Barut Tüpü (5 g. kara barut) yani 2.62 bar basınç gerekeceği anlaşılmıştır.

## Bulgular ve Analiz:

Yörünge altı sonda roketleri için görev yükünün bırakılması ve başarılı kurtarmanın yapılabilmesi çok önemli bir tasarım parametresidir.

Ayrılmalar için seçtiğimiz piroteknik malzeme kullanarak ayırma yöntemi en basit ve güvenilir yöntemlerden biri olsa da piroteknik malzeme hazır sistem olacağından ve test şansı bulunmamasından dolayı paylaşılan basınç-zaman[8] verilerinden yararlanılarak hazır SGU için modelleme yapılması ihtiyacı duyulmuştur.

SGU ile aynı basınca güvenilir bir şekilde ulaşıp test yapılabilmesi için literatürde geniş bir çalışma alanı olan kara barut üzerinden gerekli hesaplamalar yapılmıştır. 1 SGU’ün sağladığı basınçlı gaz miktarının yaklaşık 2.5 g kara barutun sağlayabileceği hesaplanmıştır.

Roketin her iki ayrılma işlemi için de 1 SGU ve 2 SGU kullanıldığı duruma göre testler yapılmıştır. 1 SGU kullanıldığı durumda ayrılmalar ancak gerçekleşse de kötü senaryolarda yeterli bulunmamıştır.

2 adet SGU kullanıldığı durumda ise ayrılmaların en kötü senaryolar için dahi sağlanabileceği testlerde görülmüştür. 2 adet SGU kullanılması yapısal dayanım açısından bir sorun etmemektedir. Bu nedenle roketin çok kritik görev adımları olan 1. Ve 2. Ayrılma için 2’şer adet SGU kullanılması kararlaştırılmıştır.

## Kaynakça

Calvert, J. (2008, Mart 3). Flash! Bang! Whiz! University of Denver: https://web.archive.org/web/20080303212017/http://mysite.du.edu/~jcalvert/phys/bang.ht m adresinden alındı

Earl 1978, Chapter 2: The Development of Gunpowder

Erik Gregersen, The Editors of Encyclopaedia Britannica. (t.y., t.y. t.y.). Ideal Gas Law. Encyclopædia Britannica: https://www.britannica.com/science/ideal-gas-law adresinden alındı

Mobley, D. (1997, Haziran). Ejection Charge Calculations. The Albuquerque Rocket Society: https://www.arsabq.org/ejection.htm adresinden alındı

Teknofest Roket Yarışması. (2025, Mayıs 14). EK-3 Sıcak Gaz Üreteci [Word dosyası]. TEKNOFEST: https://cdn.teknofest.org/media/upload/userFormUpload/EK-3_S%C4%B1cak_Gaz_%C3%9Creteci_Str6E.docx adresinden alındı

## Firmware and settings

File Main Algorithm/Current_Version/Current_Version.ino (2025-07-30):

//main.ino
#include <Wire.h>
#include <Adafruit_BMP280.h>
#include "MPU6050_6Axis_MotionApps20.h"
#include "functions.h"
#include <LoRa_E32.h>
#include <SoftwareSerial.h>
#include <TinyGPS++.h>
#include <EEPROM.h> // flasha veri yazma
#include "esp_task_wdt.h" // Task watchdog timer

#define sitsutrx 3
#define sitsuttx 1

/*
  Switch acik oldugu zaman flashtaki veri okunacak
  kapaliysa ilk acis
  roketi ucusa hazirlamak icin once switch kapali acilmali sonra sistem kapatilip switch acik olarak baslatilmali
*/

  unsigned long lora_timer;

#define INTERRUPT_PIN 2

#define SWITCH_PIN 35 // flag icin switch

volatile bool switch_state; // flag icin switch

//diger nesneler
HardwareSerial  SitSut(1);
HardwareSerial  SerialAT(2);
LoRa_E32        e32ttl(&SerialAT);
SoftwareSerial  gpsSW(GPS_RX_PIN, GPS_TX_PIN);
TinyGPSPlus     gps;

// Sensör nesneleri
Adafruit_BMP280 bmp(&Wire1);
MPU6050 mpu;

const int FlagButtonPin = 14; //*******************************************sadece flag atlama butonu
volatile bool ButtonFlag = false; //************************************sadece flag atlama butonu

void IRAM_ATTR handleInterrupt() { //****************************************************sadece flag atlama butonu
  ButtonFlag = true;
}

#pragma region timer starts timer after 10s and yukseklik
#include <Ticker.h>
void first_flag_function(){
  if(switch_state == HIGH){
    EEPROM.get(1, yukseklikraw);
    flag = EEPROM.read(0); // 0. byte'tan oku
    Serial.println("eepromdan veri okundu, veri: ");
    Serial.println(flag);
  }
  else{
    yukseklikraw = yukseklik;
    EEPROM.put(1, yukseklikraw);
    EEPROM.commit();
    flag = 0;
    EEPROM.write(0, flag);
    EEPROM.commit();
    Serial.println("Kalibrasyon Tamamlandı");
  }
}
Ticker flag_ticker;
#pragma endregion


#pragma region Kalman Filter

// Zaman adımı: dt, Python tarafından hesaplanan ortalama değere göre (0.12 s)
float dt = 0.12;  

// Kalman filtre için durum vektörü: [altitude, vertical velocity, vertical acceleration]
// Burada vertical acceleration, kontrol girişi olarak kullanılacaktır.
float m_n[3] = {0.0, 0.0, 0.0};  // Başlangıç durumu (yükseklik, dikey hız,dikey ivme)
float P_n[3][3] = { {1, 0, 0}, {0, 1, 0}, {0, 0, 1} };

// Sabit ivmeli model için sistem dinamik matrisi F:
float F[3][3] = {
  {1, dt, 0.5 * dt * dt},
  {0, 1, dt},
  {0, 0, 1}
};

// Python optimizasyonundan elde edilen Q (süreç gürültüsü kovaryansı):
float Q[3][3] = {
  {0.1, 0,   0},
  {0,   0.1, 0},
  {0,   0,   0.1}
};

// Ölçüm gürültüsü: Ölçümde yalnızca altimetre kullanıldığından, R bir skaler olarak 0.1 alınır.
float R_meas = 0.022942;  // default 0.1 metenin attigi yeni degere gore 0.022942 olarak değiştirilip test edilcek

// Ölçüm matrisi: yalnızca altimetre ölçümü kullanılır, H_new = [1, 0, 0]
float H_new[1][3] = { {1, 0, 0} };

// MPU6050 DMP için
 
volatile bool MPUInterrupt = false;
bool DMPReady = false;
uint8_t devStatus;
uint16_t packetSize;
uint8_t FIFOBuffer[64];

Quaternion q;
VectorFloat gravity;
float ypr[3];  // Yaw, Pitch, Roll

// MPU6050 DMP Interrupt Handler
void DMPDataReady() {
  MPUInterrupt = true;
}

// Yardımcı: 3x3 matris çarpımı (A * B, sonuç 3x3)
void mat3Mul(float A[3][3], float B[3][3], float C[3][3]) {
  for (int i = 0; i < 3; i++){
    for (int j = 0; j < 3; j++){
      C[i][j] = 0;
      for (int k = 0; k < 3; k++){
        C[i][j] += A[i][k] * B[k][j];
      }
    }
  }
}

// Yardımcı: 3x3 matrisin transpozu ile çarpımı (A * F^T, F^T[i][j]=F[j][i])
void mat3MulFTrans(float A[3][3], float F_mat[3][3], float C[3][3]) {
  for (int i = 0; i < 3; i++){
    for (int j = 0; j < 3; j++){
      C[i][j] = 0;
      for (int k = 0; k < 3; k++){
        C[i][j] += A[i][k] * F_mat[j][k];
      }
    }
  }
}

/*      
  Modified Kalman Filter:
  - Prediction aşamasında kontrol girişi olarak MPU6050’den okunan vertical ivme (accel_meas) kullanılır.
  - Durum güncellemesi, yalnızca altimetre (BMP280) ölçümü kullanılarak inovasyon hesaplanır.
  
  Prediction:
    x_pred[0] = m_n[0] + m_n[1]*dt + 0.5*dt^2 * accel_meas;
    x_pred[1] = m_n[1] + dt * accel_meas;
    x_pred[2] = accel_meas;    // Ölçülen ivme direkt atanır.
    
  Measurement update:
    y = alt_meas - x_pred[0];
    S = P_pred[0][0] + R_meas;
    K = P_pred(:,0) / S;
    x_updated = x_pred + K * y;
*/

void kalmanFilter_modified(float alt_meas, float accel_meas) {
  // 1. Tahmin Aşaması
  float x_pred[3];
  x_pred[0] = m_n[0] + m_n[1] * dt + 0.5 * dt * dt * accel_meas;
  x_pred[1] = m_n[1] + dt * accel_meas;
  x_pred[2] = accel_meas;
  
  // P_pred = F * P_n * F^T + Q
  float temp[3][3];
  float P_pred[3][3];
  mat3Mul(F, P_n, temp);
  mat3MulFTrans(temp, F, P_pred);
  for (int i = 0; i < 3; i++){
    for (int j = 0; j < 3; j++){
      P_pred[i][j] += Q[i][j];
    }
  }
  
  // 2. Ölçüm İnovasyonu: Sadece altimetre ölçümü kullanılır
  float y = alt_meas - x_pred[0];
  
  // 3. İnovasyon Kovaryansı: S = P_pred[0][0] + R_meas
  float S = P_pred[0][0] + R_meas;
  if (S == 0) return;
  
  // 4. Kalman Kazancı: K = P_pred(:,0) / S
  float K[3];
  K[0] = P_pred[0][0] / S;
  K[1] = P_pred[1][0] / S;
  K[2] = P_pred[2][0] / S;
  
  // 5. Durum Güncellemesi
  float x_updated[3];
  x_updated[0] = x_pred[0] + K[0] * y;
  x_updated[1] = x_pred[1] + K[1] * y;
  x_updated[2] = x_pred[2] + K[2] * y;
  
  // 6. Kovaryans Güncellemesi: P = (I - K * H_new) * P_pred, H_new = [1, 0, 0]
  float I_KH[3][3];
  for (int i = 0; i < 3; i++){
    for (int j = 0; j < 3; j++){
      float KH = (j == 0) ? K[i] : 0;
      I_KH[i][j] = (i == j ? 1.0 : 0.0) - KH;
    }
  }
  float P_updated[3][3] = { {0,0,0}, {0,0,0}, {0,0,0} };
  for (int i = 0; i < 3; i++){
    for (int j = 0; j < 3; j++){
      for (int k = 0; k < 3; k++){
        P_updated[i][j] += I_KH[i][k] * P_pred[k][j];
      }
    }
  }
  
  // Global durum ve kovaryans güncellemesi
  for (int i = 0; i < 3; i++){
    m_n[i] = x_updated[i]; //(dikey hız )
    for (int j = 0; j < 3; j++){
      P_n[i][j] = P_updated[i][j];
    }
  }
}

#pragma endregion

void setup() {
  Serial.begin(115200);
  // SitSut.begin(115200, SERIAL_8N1, sitsutrx, sitsuttx);
  SerialAT.begin(9600, SERIAL_8N1, LORA_RX, LORA_TX); //lora ve gps
  Wire.begin(MPU_SDA, MPU_SCL);
  Wire1.begin(BMP_SDA, BMP_SCL);
  Wire.setClock(400000);

  gpsSW.begin(GPS_BAUD); //lora
  e32ttl.begin(); // lora

  if (!EEPROM.begin(5/* Kaç byte'lık yer ayıracağın (1–512 arası)*/)) {
    Serial.println("EEPROM cannot started");
    return;
  }


  pinMode(SWITCH_PIN, INPUT); // flag icin switch

  switch_state = digitalRead(SWITCH_PIN); // flag icin switch

  pinMode(SURUKLENME_PARASUT_PIN, OUTPUT);
  pinMode(ANA_PARASUT_PIN, OUTPUT);

  digitalWrite(SURUKLENME_PARASUT_PIN, LOW);
  digitalWrite(ANA_PARASUT_PIN, LOW);


  // Optimize edilmiş Q ve R parametrelerini ekrana yazdırıyoruz:
  Serial.println("Optimized Kalman Filter Parameters:");
  Serial.println("Q:");
  Serial.println("0.1  0    0");
  Serial.println("0    0.1  0");
  Serial.println("0    0    0.1");
  Serial.println("R:");
  Serial.println("0.1");
  
  // BMP280 Başlatma (I2C adresi 0x76 veya 0x77 olabilir)
  if (!bmp.begin(0x76)) {
    Serial.println("BMP280 sensor not detected.");
    while (1);
  }

  Serial.println("Initializing MPU6050...");
  mpu.initialize();
  pinMode(INTERRUPT_PIN, INPUT);
  Serial.println(mpu.testConnection() ? "MPU6050 connection successful" : "MPU6050 connection failed");
  
  devStatus = mpu.dmpInitialize();
  if (devStatus == 0) {
    mpu.CalibrateAccel(6);
    mpu.CalibrateGyro(6);
    mpu.PrintActiveOffsets();
    
    mpu.setDMPEnabled(true);
    attachInterrupt(digitalPinToInterrupt(INTERRUPT_PIN), DMPDataReady, RISING);
    Serial.println("DMP ready!");
    DMPReady = true;
    packetSize = mpu.dmpGetFIFOPacketSize();
  } else {
    Serial.print("DMP Initialization failed (code ");
    Serial.print(devStatus);
    Serial.println(")");
  }

  flag_ticker.once(1.0/*second*/, first_flag_function); //timer starts after 10s
  pinMode(FlagButtonPin, INPUT_PULLDOWN);  // Buton için dahili pull-up *********************************************sadece flag atlama butonu
  attachInterrupt(digitalPinToInterrupt(FlagButtonPin), handleInterrupt, FALLING); //*****************************sadece flag atlama butonu

  lora_timer = millis();


  esp_task_wdt_config_t twdt_config = { // task watchdog configuraiton
    .timeout_ms = 3000, // 3 saniye içinde resetlenmeli
    .idle_core_mask = 0, // idle task izlenmiyor
    .trigger_panic = true
  };

  esp_task_wdt_init(&twdt_config); // Watchdog’u başlat
  esp_task_wdt_add(NULL);          // Mevcut görev (loop task) TWDT’ye abone edildi
}

uint8_t scenario;

void loop() {

  /*
  if ( sit test verisi) {
    scenario = 1;
  }
  else if (sut test verisi) {
    scenario = 2;
  }
  else {
    scenario = 0;
  }
  */

  float altitude;

  scenario = 1;
  
  switch(scenario){
    case 0: // default
      if (!DMPReady) return;
      // MPU6050'dan verileri oku (sadece vertical ivme için)
      if (mpu.dmpGetCurrentFIFOPacket(FIFOBuffer)) { 
        mpu.dmpGetQuaternion(&q, FIFOBuffer);
        mpu.dmpGetGravity(&gravity, &q);
        mpu.dmpGetYawPitchRoll(ypr, &q, &gravity); // Bu satır eklendi, böylece ypr güncellenir.
      }
      
      // BMP280'dan altimetre ölçümü (deniz seviyesi basıncı 1013.25 hPa)
      altitude = bmp.readAltitude(1013.25);
      // MPU6050'dan okunan vertical ivme: gravity.z (kontrol girişi olarak kullanılacak)
      accel_x = gravity.x;
      accel_y = gravity.y;
      accel_z = gravity.z;

      // Kalman filtresi uygulaması: altimetre ölçümü, kontrol girişi olarak accel_z
      kalmanFilter_modified(altitude, accel_z);

      //m_n[] lerin normal adlara esitlenmesi
      yukseklik = m_n[0] - yukseklikraw;
      hiz = m_n[1];
      ivme = m_n[2];

      // Kalman filtresi sonuçları: m_n[0] = güncellenmiş altimetre, m_n[1] = hız, m_n[2] = ivme
      // Serial.print(" | Altituderaw: "); Serial.print(yukseklikraw);
      // Serial.print(" | Altitude: "); Serial.print(yukseklik);
      // Serial.print(" | Speed: "); Serial.print(hiz);
      // Serial.print(" | Accel: "); Serial.print(ivme);

      // Serial.print(" | Current Flag: "); Serial.println(flag);


      pitch = ypr[1];
      roll = ypr[2];
      yaw = ypr[0];

      // MPU6050 açıları (Yaw, Pitch, Roll) seri yazdırma
      //Serial.print("Yaw: "); Serial.print(ypr[0], 4);
      //Serial.print(" | Pitch: "); Serial.print(ypr[1], 4);
      //Serial.print(" | Roll: "); Serial.println(ypr[2], 4);

      // Derece cinsinden açıları da yazdırma
      yawDeg = ypr[0] * 180.0 / PI;
      pitchDeg = ypr[1] * 180.0 / PI;
      rollDeg = ypr[2] * 180.0 / PI;
      //Serial.print("Yaw (°): "); Serial.print(yawDeg, 2);
      //Serial.print(" | Pitch (°): "); Serial.print(pitchDeg, 2);
      //Serial.print(" | Roll (°): "); Serial.println(rollDeg, 2);

      millis_counter = millis() - millis_saved;

      // if (ButtonFlag) {//*****************************************sadece flag atlama butonu
      //   ButtonFlag = false;             // Bayrağı sıfırla
      //   Serial.println("Flag atlandi");       // Kesmede değil, burada yazdır
      //   flag++;
      //   EEPROM.write(0, flag); //veriyi flaha yaz
      //   EEPROM.commit();  // veriyi kalicilastir
      // }

      // if (switch_state == HIGH){
      //   Serial.print("switch is high and eeprom value is ");
      //   int asd = EEPROM.read(0); // 0. byte'tan oku
      //   Serial.println(asd);
        
      // }
      // else if(switch_state == LOW){
      //   Serial.println("switch is low");
      // }
      
      call_lora();

      switch(flag){
        case 0:
          kalkis();
          break;
        
        case 1:
          burnout();
          break;

        case 2:
          apogee();
          break;

        case 3:
          parasut_tekrarla(0/* 0: Suruklenme parasutu, 1: Ana parasut */);
          break;

        case 4:
          parasut();
          break;

        case 5:
          alcalma();
          parasut_tekrarla(1/*;Ana parasut icin*/);
          break;
      }
      
      break;
    case 1: // sit test
      if (!DMPReady) return;
      // MPU6050'dan verileri oku (sadece vertical ivme için)
      if (mpu.dmpGetCurrentFIFOPacket(FIFOBuffer)) { 
        mpu.dmpGetQuaternion(&q, FIFOBuffer);
        mpu.dmpGetGravity(&gravity, &q);
        mpu.dmpGetYawPitchRoll(ypr, &q, &gravity); // Bu satır eklendi, böylece ypr güncellenir.
      }

      accel_x = gravity.x;
      accel_y = gravity.y;
      accel_z = gravity.z;
      pitch = ypr[1];
      roll = ypr[2];
      yaw = ypr[0];

      sit();
      break;
    case 2: // sut test
      sut();
      break;
  }
  esp_task_wdt_reset(); // watchdog'u besle
}

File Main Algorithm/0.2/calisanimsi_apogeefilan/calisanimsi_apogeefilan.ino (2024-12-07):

// Basic demo for accelerometer readings from Adafruit MPU6050

#include <Adafruit_MPU6050.h>
#include <Adafruit_Sensor.h>
#include <Wire.h>
#include <SPI.h>
#include <Adafruit_BMP280.h>

#define BMP_SCK  (13)
#define BMP_MISO (12)
#define BMP_MOSI (11)
#define BMP_CS   (10)

#define LED1 33
#define LED2 25
#define LED3 26
#define LED4 27

bool apogee(float altitude, float accel);
bool parachute(float altitude); // if altitude under 600m return true



Adafruit_MPU6050 mpu;
Adafruit_BMP280 bmp; // I2C

  float p0 = 1034.7; // havadurumundan deniz seviyesi basınç değeri hPa

  float axOffset = 0, ayOffset = 0, azOffset = 0;
  float gxOffset = 0, gyOffset = 0, gzOffset = 0;
  float altitudeoffset = 0;

  int x = 0; // used for switch cases

void setup(void) {

  Serial.begin(115200);
  while (!Serial)
    delay(10); // will pause Zero, Leonardo, etc until serial console opens

  Serial.println("Adafruit MPU6050 test!");

  // Try to initialize!
  if (!mpu.begin()) {
    Serial.println("Failed to find MPU6050 chip");
    while (1) {
      delay(10);
    }
  }
  Serial.println("MPU6050 Found!");

  mpu.setAccelerometerRange(MPU6050_RANGE_8_G);
  Serial.print("Accelerometer range set to: ");
  switch (mpu.getAccelerometerRange()) {
  case MPU6050_RANGE_2_G:
    Serial.println("+-2G");
    break;
  case MPU6050_RANGE_4_G:
    Serial.println("+-4G");
    break;
  case MPU6050_RANGE_8_G:
    Serial.println("+-8G");
    break;
  case MPU6050_RANGE_16_G:
    Serial.println("+-16G");
    break;
  }
  mpu.setGyroRange(MPU6050_RANGE_500_DEG);
  Serial.print("Gyro range set to: ");
  switch (mpu.getGyroRange()) {
  case MPU6050_RANGE_250_DEG:
    Serial.println("+- 250 deg/s");
    break;
  case MPU6050_RANGE_500_DEG:
    Serial.println("+- 500 deg/s");
    break;
  case MPU6050_RANGE_1000_DEG:
    Serial.println("+- 1000 deg/s");
    break;
  case MPU6050_RANGE_2000_DEG:
    Serial.println("+- 2000 deg/s");
    break;
  }

  mpu.setFilterBandwidth(MPU6050_BAND_21_HZ);
  Serial.print("Filter bandwidth set to: ");
  switch (mpu.getFilterBandwidth()) {
  case MPU6050_BAND_260_HZ:
    Serial.println("260 Hz");
    break;
  case MPU6050_BAND_184_HZ:
    Serial.println("184 Hz");
    break;
  case MPU6050_BAND_94_HZ:
    Serial.println("94 Hz");
    break;
  case MPU6050_BAND_44_HZ:
    Serial.println("44 Hz");
    break;
  case MPU6050_BAND_21_HZ:
    Serial.println("21 Hz");
    break;
  case MPU6050_BAND_10_HZ:
    Serial.println("10 Hz");
    break;
  case MPU6050_BAND_5_HZ:
    Serial.println("5 Hz");
    break;
  }

  //bmp280

  while ( !Serial ) delay(100);   // wait for native usb
  Serial.println(F("BMP280 test"));
  unsigned status;
  //status = bmp.begin(BMP280_ADDRESS_ALT, BMP280_CHIPID);
  status = bmp.begin(0x76);
  if (!status) {
    Serial.println(F("Could not find a valid BMP280 sensor, check wiring or "
                      "try a different address!"));
    Serial.print("SensorID was: 0x"); Serial.println(bmp.sensorID(),16);
    Serial.print("        ID of 0xFF probably means a bad address, a BMP 180 or BMP 085\n");
    Serial.print("   ID of 0x56-0x58 represents a BMP 280,\n");
    Serial.print("        ID of 0x60 represents a BME 280.\n");
    Serial.print("        ID of 0x61 represents a BME 680.\n");
    while (1) delay(10);
  }

  /* Default settings from datasheet. */
  bmp.setSampling(Adafruit_BMP280::MODE_NORMAL,     /* Operating Mode. */
                  Adafruit_BMP280::SAMPLING_X2,     /* Temp. oversampling */
                  Adafruit_BMP280::SAMPLING_X16,    /* Pressure oversampling */
                  Adafruit_BMP280::FILTER_X16,      /* Filtering. */
                  Adafruit_BMP280::STANDBY_MS_1); /* Standby time. */

  //bmp280end

  sensors_event_t a, g, temp;
  mpu.getEvent(&a, &g, &temp);

    int up_to = 1000;

    for (int i = 0; i < up_to; i++) {

    axOffset += a.acceleration.x;
    ayOffset += a.acceleration.y;
    azOffset += a.acceleration.z;
    gxOffset += g.gyro.x;
    gyOffset += g.gyro.y;
    gzOffset += g.gyro.z;
    altitudeoffset += bmp.readAltitude(p0);

    delay(5);
  }

  axOffset /= up_to;
  ayOffset /= up_to;
  azOffset /= up_to;
  gxOffset /= up_to;
  gyOffset /= up_to;
  gzOffset /= up_to;
  altitudeoffset /= up_to;


  pinMode(LED1, OUTPUT);
  pinMode(LED2, OUTPUT);
  pinMode(LED3, OUTPUT);
  pinMode(LED4, OUTPUT);


  Serial.println("");
  delay(100);

}

void loop() {

    sensors_event_t a, g, temp;
  mpu.getEvent(&a, &g, &temp);

  float altitude;
  float altitude0;
  altitude0 = bmp.readAltitude(p0);
  altitude = (altitude0 - altitudeoffset); // altitude

  /* Print out the values */
  Serial.print("Acceleration X: ");
  Serial.print(a.acceleration.x - axOffset);
  Serial.print(", Y: ");
  Serial.print(a.acceleration.y - ayOffset);
  Serial.print(", Z: ");
  Serial.print(a.acceleration.z - azOffset +10.1); // gravity reg
  Serial.println(" m/s^2");

  Serial.print("Rotation X: ");
  Serial.print(g.gyro.x - gxOffset);
  Serial.print(", Y: ");
  Serial.print(g.gyro.y - gyOffset);
  Serial.print(", Z: ");
  Serial.print(g.gyro.z - gzOffset);
  Serial.println(" rad/s");

  //Serial.print("Temperature: ");
  //Serial.print(temp.temperature);
  //Serial.println(" degC");

  //Serial.println("");

  //bmp280start

  //Serial.print(F("Temperature = "));
  //Serial.print(bmp.readTemperature());
  //Serial.println(" *C");

  //Serial.print(F("Pressure = "));
  //Serial.print(bmp.readPressure());
  //Serial.println(" Pa");

  Serial.print(F("Approx altitude = "));
  Serial.print(altitude); /* Adjusted to local forecast! */
  Serial.println(" m");

  Serial.println();

  switch (x)
  {
  case 0:
    if(a.acceleration.z < 8)  // launch
    {
        digitalWrite(LED1, HIGH);
        x++;
        break;
    }
    break;
  case 1:
    if(a.acceleration.z > 8) // burnout
    {
        digitalWrite(LED2, HIGH);
        x++;
        break;
    }
    break;
  case 2:
    //if(apogee(altitude, a.acceleration.z)) // apogee
    if(a.acceleration.z < -8)
    {
        digitalWrite(LED3, HIGH);
        x++;
        break;
    }
    break;
  case 3:
    if(parachute(altitude)) // parachute
    {
        digitalWrite(LED4, HIGH);
        x++;
        break;
    }
    break;
  }

  //bmp280end

  delay(500);

}

bool apogee(float altitude, float accel)
'{
  int y = 0;
  float altitude0;
  for(int i = 0; i < 3; i++)
  {
      altitude0 = altitude;
      delay(5);
      if(altitude0 < altitude)
      {
          return false;
      }
  }
  y++;

  if(accel > 0)
  {
    y++;
  }
  if(y = 2)
  {
    return true;
  }
}'

bool parachute(float altitude) // if altitude under 600m return true
{
    for(int i = 0; i < 3; i++)
    {
        if(altitude > 600)
        {
            return false;
        }
    }
    return true;
}

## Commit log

2025-04-30 koddaki fonksiyonlari parcaladim
    kalkis, apogee, parasut, alcalma fonksiyonları functions.cpp olarak ayrı bir dosyaya koyuldu. fonksiyonların içindeki değerler güncellendi. esp32 de testi yapılamadı esp'm yok.
2025-05-01 Rename ÖTR ORTAK ŞABLONN.pdf to 2025_ÖTR ORTAK ŞABLON.pdf
2025-05-01 Rename OSTİMTech Roket Takımı KTR 2024 (1).pdf to 2024 KTR.pdf
2025-05-01 Update and rename 2025_ÖTR ORTAK ŞABLON.pdf to 2025 ÖTR.pdf
2025-05-01 Rename KTR_Şablonu_2025_cukOz.docx to 2025 KTR ŞABLON.docx
2025-05-01 Rename OstimTech Roket Takımı ÖTR 2024.pdf to 2024 ÖTR.pdf
2025-05-12 test gününde düzenlenen kod
    kodu 1.1 ve functions.cpp, functions.h olarak ayırmak işe yaramadı compile etti ama bir şekilde verileri işlerken sıkıntı çıktı ve test günü ledi yakamamamızla sonuçlandı. bu kodu 1.0 ı düzenleyerek 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
2025-06-12 Version Kategorizasyonunda değişiklik
    Bundan sonra daha önceki koddan yapılan değişiklikleri daha rahat görmek için tüm düzenlenmeler Current_Version üzerinden yapılacak. Ardından Çalışma bittikten sonra versiyonu kayıt etmek için adland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
2025-06-15 2.0 Let's Gooo!
    Koddaki .ino .cpp .h ayırmaları düzeltildi artık çalışıyor. Koda millis kullanarak ortalma alma eklendi (temel mantık doğru olmasına rağmen baya uğraştırdı) . Timer ı entegre ettim 10 sn kalibrasyonu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
2025-06-29 3.1 ►► Flag artik flashe kayit ediliyor ve Pin high lar eklendi◄◄
    <EEPROM.h> kullanilarak flasha kayit etme eklendi. Switch acik oldugu zaman flashtaki veri okunacak kapaliysa 0 dan baslayacak. Ana parasut ve Suruklenme parasutu icin pinler eklendi ve yakma kodlari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
    havadayken raw yüksekliğin değiştiği hata giderildi. artık flash okuma modunda yeniden başladığında raw yükseklik değerinide flsahtan okuyacak.
    havada başlatıldığında ilk seferde her zaman 0 olarak okunana avarage_in_given_time değişken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
2025-07-07 Lora haberleşmesi düzenlendi ve Kalman hızlandırıldı
    Lora artik ticker kullanilarak timer interruptla 200 ms olarak ayarlandi ve ölçümlere göre 193 +- 3 ms gönderiyor
    Kalman filtresini yavaşlatan tüm faktörler kaldırıldı. Artık 300ms içinde hız olması gereken değere geliyor. Timer hala 1 saniye sonra başlatıyor Flagleri.
    call_lora fonksiyonu oluşturuldu. eğer flag başlangıç flagine eşit değilse lora fonksiyonunu çağırıyor. kod çalışırken ilk 1 saniyede kalibrasyon yaparken loranın veri göndermemesini sağlıyor. call_l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
    çok fazla test için ve artık kullanmad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
2025-07-11 KTR Döküman
    [EK-1 OSTİMTechRoketTakımı_KTR_Kütle_Bütçesi_2025.xlsx, EK-3 OSTİMTechRoketTakımı KTR HTEA 2025.xlsx]
2025-07-11 gps fix
    fixed - calling lora with ticker.h causes gps failure
    [3.3_gps_fix.ino, functions.cpp, functions.h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]
2025-07-11 minimal schanges
    teamid printleme eklendi ve bikaç sastır düzenlendi
2025-07-13 Update CurrentVersion.ino
    watchdog addition
2025-08-01 receiver güncelleme
    receiver 2 ye ayrıldı
    yaw pitch roll gönderilmeyeceği için koddan çıkartıldı.
    artık receiver a gelen crc ile hesaplanan uyuşmuyorsa veriyi printlemiyor.
